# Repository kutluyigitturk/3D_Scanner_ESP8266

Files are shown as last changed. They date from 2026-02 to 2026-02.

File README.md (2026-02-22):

<div align="center">

# 3D_Scanner_ESP8266






**A real-time 3D point cloud scanner over WiFi using Arduino Uno, ESP8266 and VL53L0X laser distance sensor.**

</div>

---

## Hardware

| Component | Quantity |
|---|---|
| Arduino Uno | 1 |
| ESP8266-01S WiFi Module | 1 |
| VL53L0X Laser Distance Sensor | 1 |
| MG90S Servo Motor (Pan,Tilt) | 2 |
| AMS1117 3.3V Voltage Regulator Module | 1 |
| USB to TTL - CP2102 | 1 |
| 3D Printing Chasis | 1 |

---

## Wiring

| Component | Arduino Pin | Note |
|---|---|---|
| Servo Pan | D9 | PWM |
| Servo Pan | 5V | Power |
| Servo Pan | GND | Ground |
| Servo Tilt | D10 | PWM |
| Servo Tilt | 5V | Power |
| Servo Tilt |GND | Ground |
| VL53L0X SDA | A4 | I2C Data |
| VL53L0X SCL | A5 | I2C Clock |
| VL53L0X VIN | 3V3 | Power |
| VL53L0X GND | GND | Ground |
| ESP8266 RX | D3 (SoftSerial TX) | Direct connection |
| ESP8266 TX | D2 (SoftSerial RX) | Direct connection |
| ESP8266 CH_PD,VCC | 3V3 | Power |
| ESP8266 GND | GND | Ground |

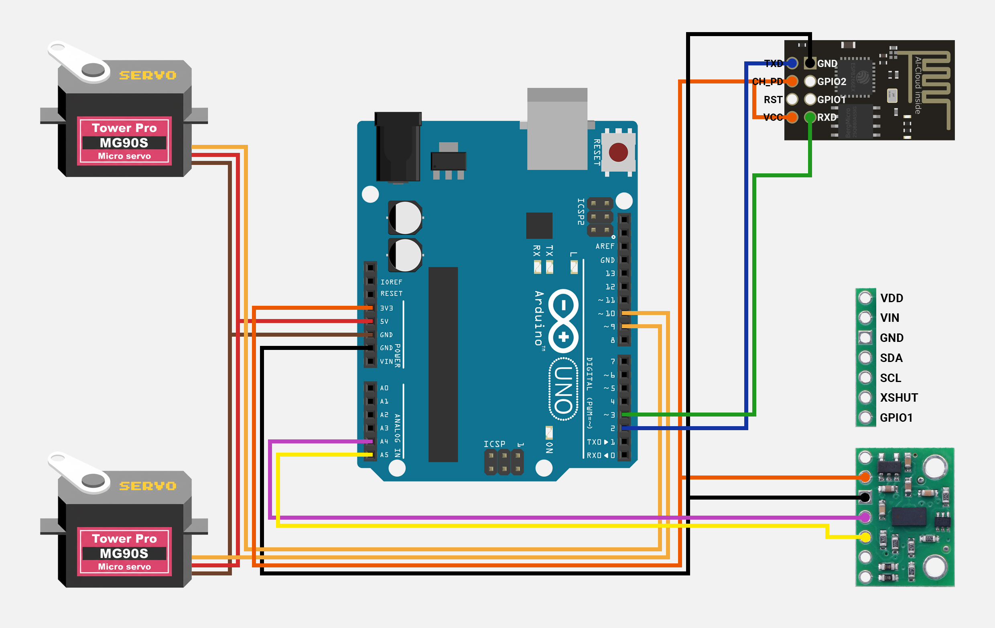
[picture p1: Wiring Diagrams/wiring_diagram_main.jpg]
Main Wiring Diagram


---

## Setup

### 1. Libraries

Install the following libraries via Arduino IDE Library Manager:

- `VL53L0X` — Pololu
- `Servo` — Arduino Built-in
- `SoftwareSerial` — Arduino Built-in
- `ESP8266WiFi` — ESP8266 Community
- `ESP8266WebServer` — ESP8266 Community
- `LittleFS` — ESP8266 Community

### 2. ESP8266 Board Support

Go to **File > Preferences > Additional Board Manager URLs** and add:

```
https://arduino.esp8266.com/stable/package_esp8266com_index.json
```

Then install the `esp8266` package from **Tools > Board Manager**.

### 3. Flash Size

Before uploading to ESP8266, set:

**Tools > Flash Size > `4MB (FS:2MB OTA:~1MB)`**

LittleFS requires a dedicated flash partition to store scan data.

### 4. Upload Order

Upload `ESP8266_Server.ino` to the ESP8266 first, then upload `Uno_Controller.ino` to the Arduino Uno.

---

## Usage

1. Power on the system — the ESP8266 will create a WiFi access point named **`3D_Scanner_Project`**.
2. Connect your phone or computer to this network. Password: **`12345678`**
3. Open a browser and go to **`192.168.4.1`**.
4. Navigate to **`192.168.4.1/scan`** to start a scan.
5. Once the scan is complete, return to the main page — the point cloud will be rendered in WebGL.

### Endpoints

| Address | Function |
|---|---|
| `/scan` | Starts a new scan |
| `/status` | Returns current status as JSON |
| `/reset` | Clears previous scan data |
| `/format` | Formats the LittleFS filesystem |

---

## Adjusting Pan-Tilt Angles

You can customize the scan area by editing the configuration block at the top of `Uno_Controller.ino`:

```cpp
const int YAW_MIN  = 0;   // Pan start angle  (°)
const int YAW_MAX  = 80;  // Pan end angle    (°)
const int PITCH_MIN = 0;  // Tilt start angle (°)
const int PITCH_MAX = 90; // Tilt end angle   (°)

const int STEP_YAW   = 2; // Step size — smaller = more points, slower scan
const int STEP_PITCH = 2;

const float VALID_MIN = 0.04f; // Valid distance range (meters)
const float VALID_MAX = 0.30f;
```

---

## Flashing the ESP8266-01S

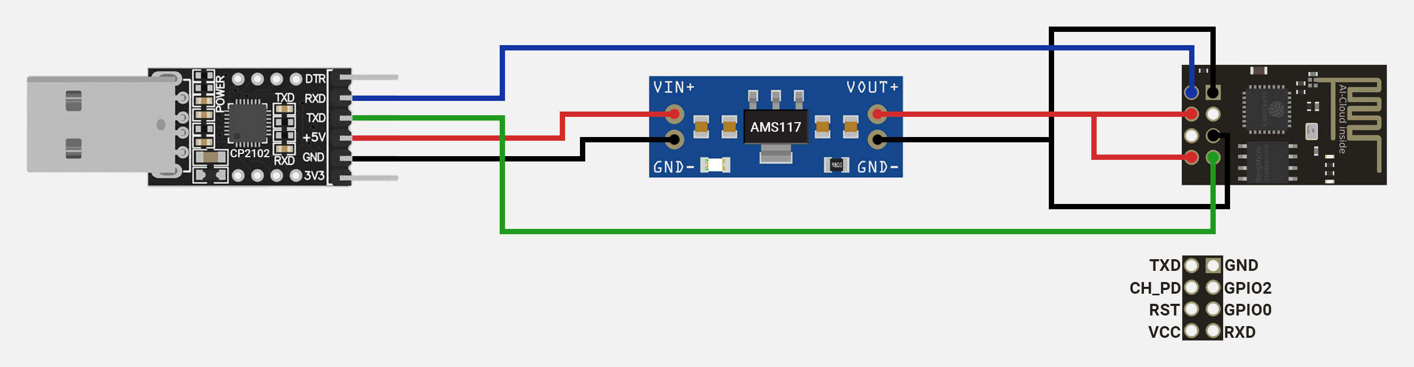
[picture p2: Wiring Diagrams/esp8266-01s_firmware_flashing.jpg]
ESP8266-01S Flashing Setup


### ESP8266-01S Firmware Flashing Procedure
This section details the hardware setup required to flash custom firmware onto the ESP8266-01S using the Arduino IDE. Due to the minimal pin output of the ESP-01S, a special USB-TTL serial converter is required for programming.

#### Critical Power Supply Considerations
Most USB-TTL converters provide a maximum of 50–100mA from the 3.3V pin, but the ESP8266-01S can draw up to 170–300mA during programming. Insufficient current causes:
- Brownout reset (continuous reset due to voltage drop)
- Connection drops during firmware upload
- "Failed to connect to ESP8266" errors
- Risk of permanent damage to the module

#### AMS1117-3.3 Regulator Solution
The AMS1117-3.3 linear voltage regulator solves this by providing a stable 3.3V/800mA from the 5V USB supply.

**Key connections:**

1. **GND** — Connect ESP-01S GND to AMS1117 GND.
2. **VCC & CH_PD** — Connect ESP-01S VCC and CH_PD (Chip Enable) to AMS1117 VOUT+.
   > ⚠️ Do **not** power the ESP-01S directly from the USB-TTL adapter's 3.3V pin — it cannot supply sufficient current.
3. **TX/RX** — Cross-connect the serial lines:
   - ESP-01S `TXD` → USB-TTL `RXD`
   - ESP-01S `RXD` → USB-TTL `TXD`
4. **Flashing Mode** — Connect ESP-01S `GPIO0` directly to GND. This puts the module into bootloader mode, ready to receive new firmware.

---

## 3D Printable Parts

The `3D Printable Parts/` folder contains all parts needed to assemble the scanner mechanism.

The tripod used in this project is sourced from:
**[Folding Tripod — MakerWorld](https://makerworld.com/tr/models/671280-folding-tripod-two-sizes?from=search#profileId-599018)**

---

## Inspiration

This project is inspired by the original ESP8266 3D scanner by **[bitluni](https://bitluni.net/3d-scanner)**.

---

## License

This project is licensed under the [MIT License](LICENSE).

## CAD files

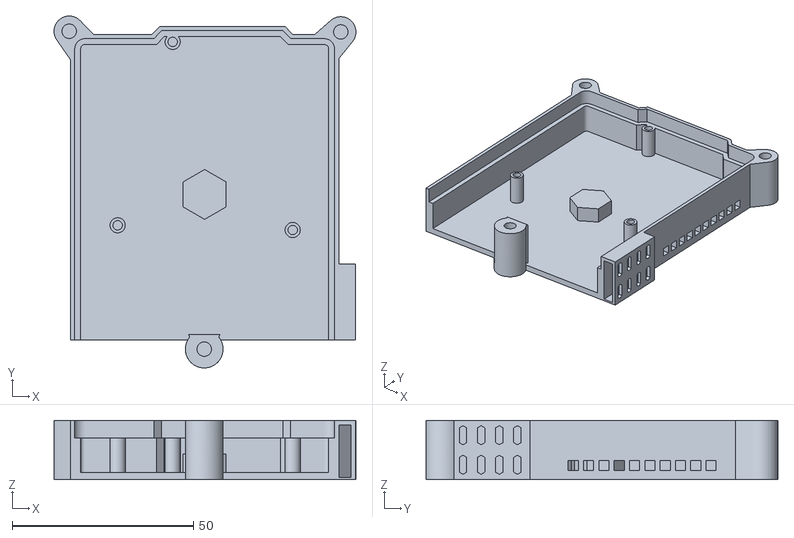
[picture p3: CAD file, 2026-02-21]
3D Printable Parts/Base.stl
83.3 x 97.0 x 16.3

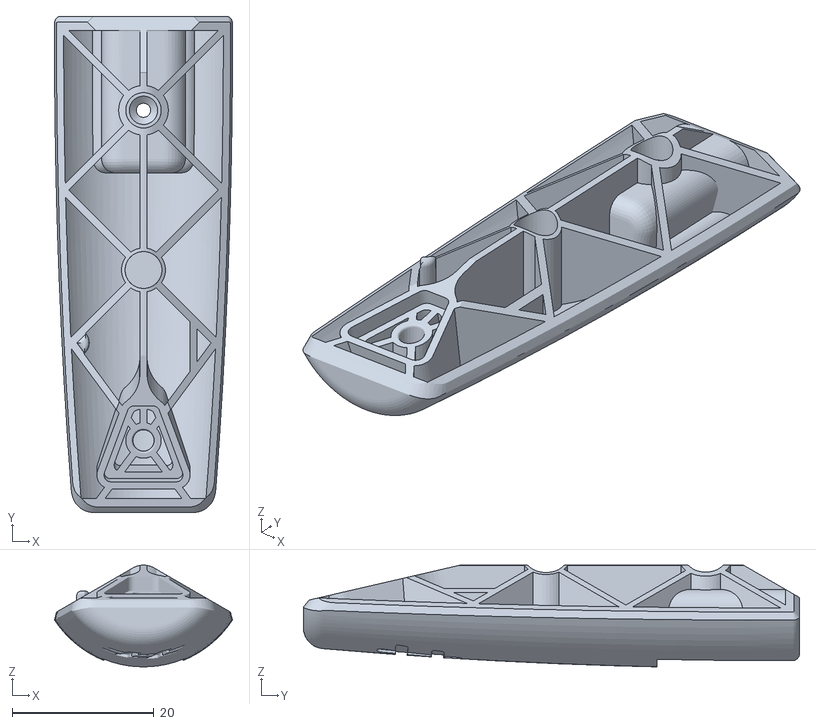
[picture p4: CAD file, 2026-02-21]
3D Printable Parts/Tripod/Leg_small.stl
25.1 x 70.0 x 14.4

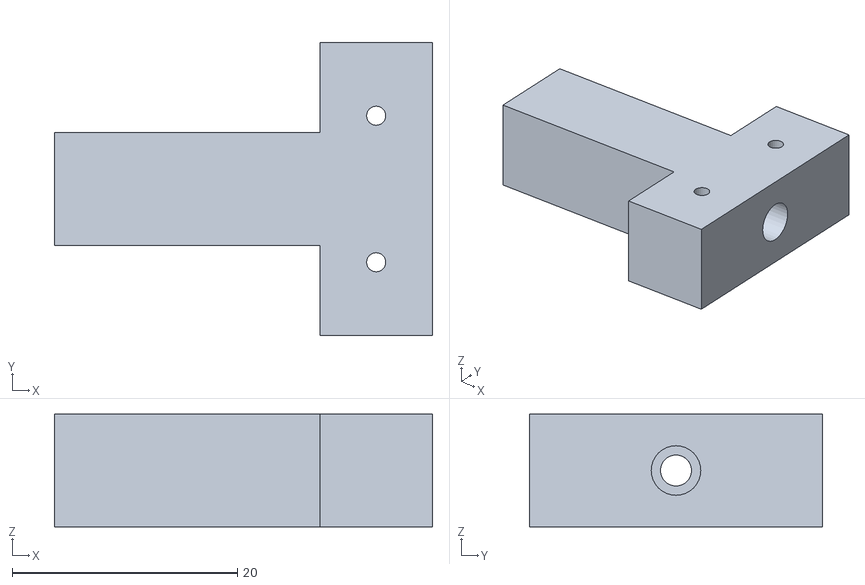
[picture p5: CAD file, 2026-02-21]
3D Printable Parts/Laser Sensor Mount.stl
33.5 x 26.0 x 10.0

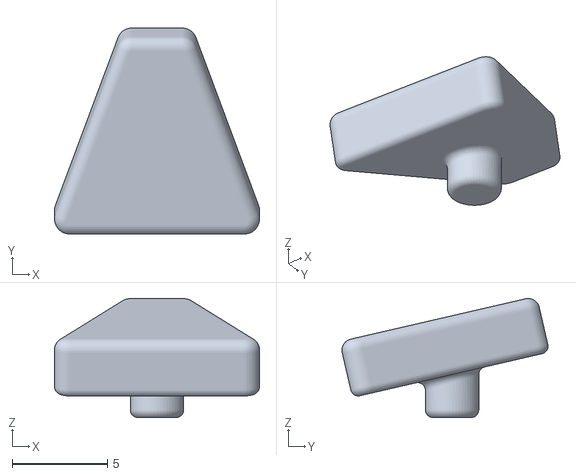
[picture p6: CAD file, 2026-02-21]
3D Printable Parts/Tripod/Foot Pad.stl
10.7 x 10.8 x 6.24

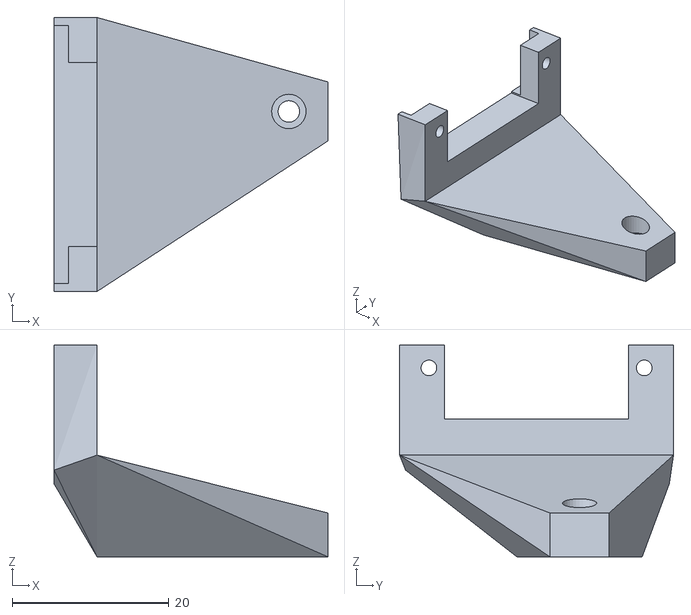
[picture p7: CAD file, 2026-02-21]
3D Printable Parts/Tilt Servo Mount.stl
35.0 x 35.0 x 27.0

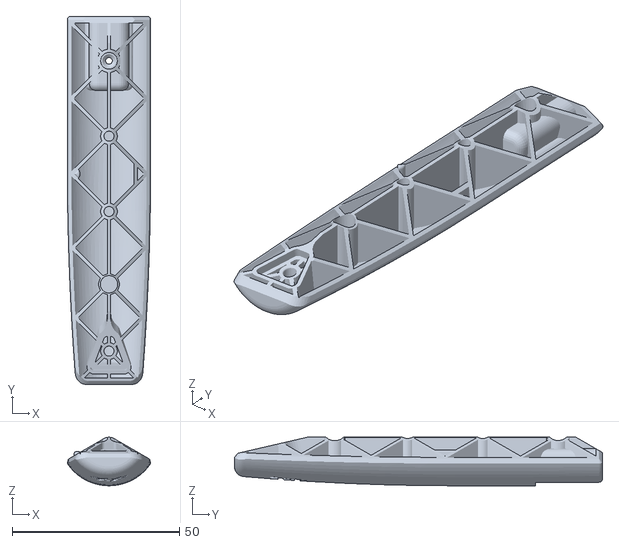
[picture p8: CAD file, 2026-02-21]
3D Printable Parts/Tripod/LegLarge.stl
24.9 x 110.0 x 14.5

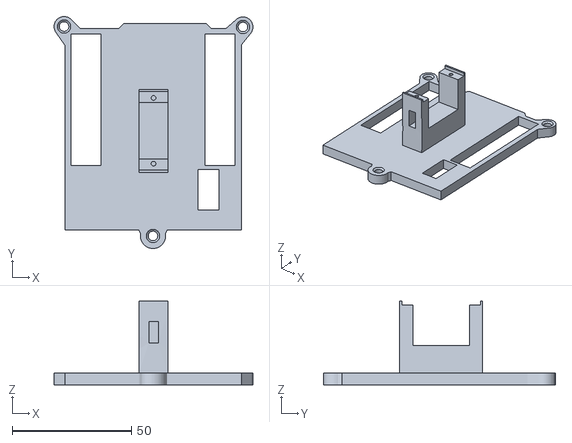
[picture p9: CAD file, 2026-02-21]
3D Printable Parts/Top.stl
83.3 x 97.1 x 35.0

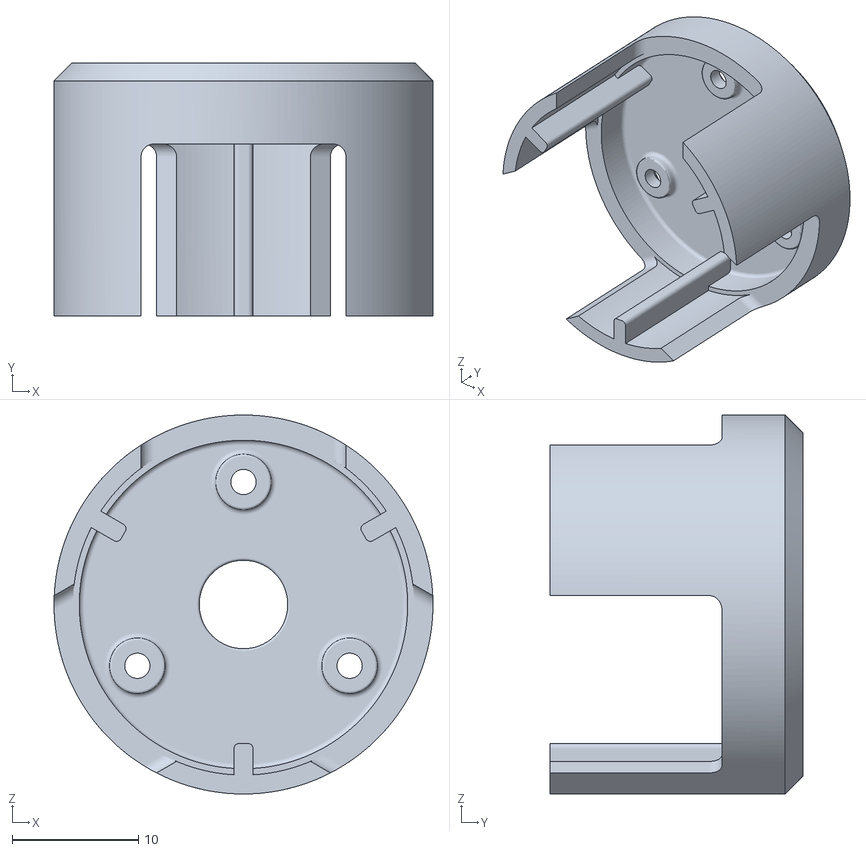
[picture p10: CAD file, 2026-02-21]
3D Printable Parts/Tripod/Cover.stl
30.0 x 20.0 x 30.0

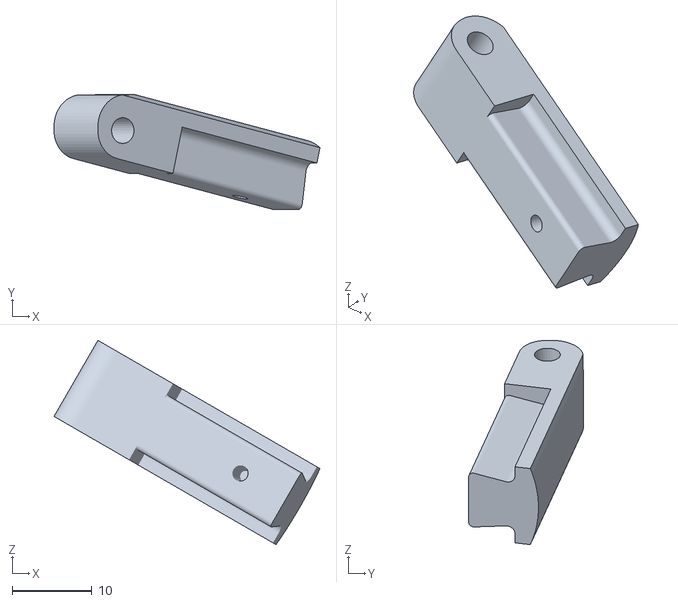
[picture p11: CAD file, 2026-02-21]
3D Printable Parts/Tripod/Stud.stl
33.3 x 14.4 x 25.6

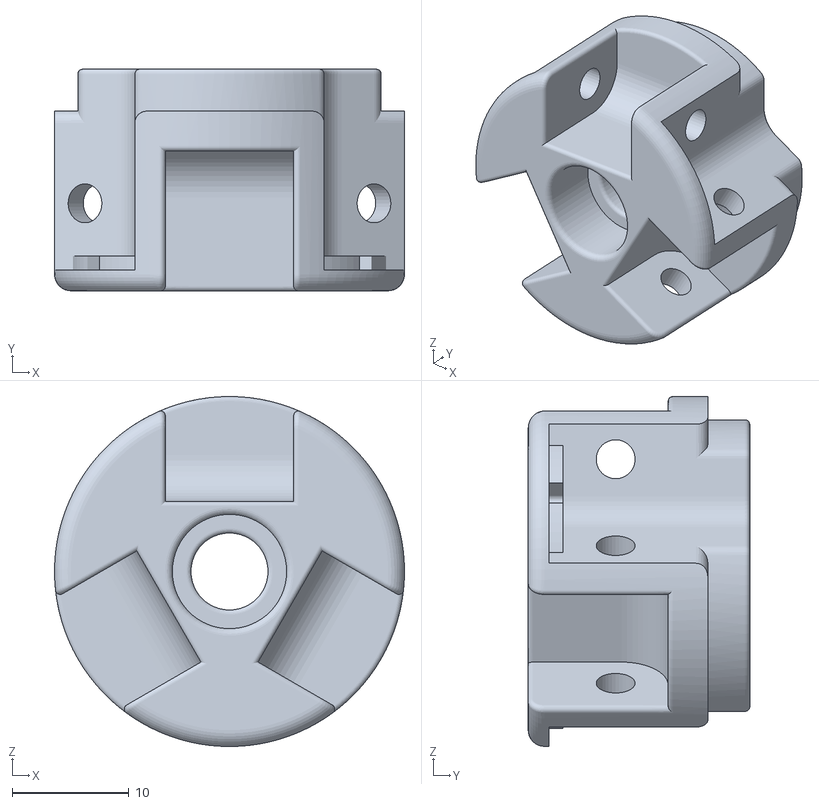
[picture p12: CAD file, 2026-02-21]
3D Printable Parts/Tripod/Center.stl
30.0 x 19.0 x 30.0

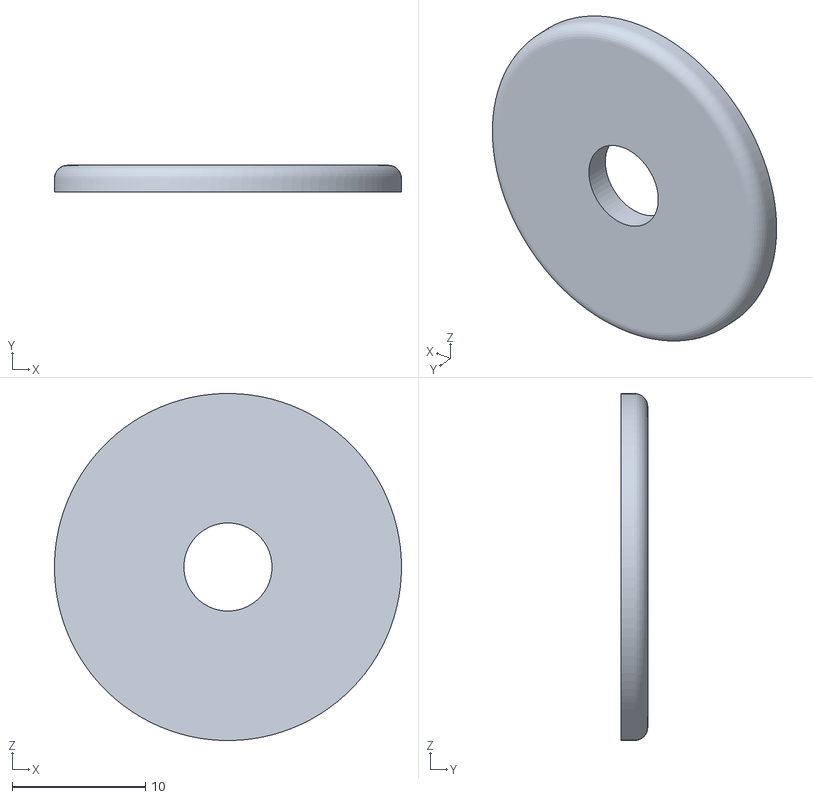
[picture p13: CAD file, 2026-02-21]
3D Printable Parts/Tripod/TPU_pad.stl
26.0 x 2.00 x 26.0

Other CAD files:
3D Printable Parts/Tripod/LegLargeBolt.stl
3D Printable Parts/Tripod/Leg_Small_Bolt.stl

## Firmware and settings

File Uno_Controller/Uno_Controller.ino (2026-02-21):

/*
 * ============================================================
 *  3D SCANNER — Arduino Uno Controller
 *
 *  [1] Angle settings moved into a clean CONFIGURATION block.
 *  [2] ADAPTIVE MEDIAN FILTER:
 *      - Empty area (no object) → 1 fast reading, discard if invalid.
 *      - Object detected        → take 3 readings, return median.
 *      Empty areas are swept quickly while object accuracy is preserved.
 *
 *  WIRING:
 *    Servo Yaw   → D9    Servo Pitch → D10
 *    VL53L0X SDA → A4    VL53L0X SCL → A5
 *    ESP8266 RX  ← D3    ESP8266 TX  → D2
 * ============================================================
 */

#include <Wire.h>
#include <VL53L0X.h>
#include <Servo.h>
#include <SoftwareSerial.h>

SoftwareSerial espSerial(2, 3);
VL53L0X sensor;
Servo yawServo;
Servo pitchServo;

// ╔══════════════════════════════════════════════════════════╗
// ║              >>> CONFIGURE HERE <<<                      ║
// ╠══════════════════════════════════════════════════════════╣
// ║  Pan (horizontal) and Tilt (vertical) angle limits       ║
// ║  Servos physically operate between 0–180°.               ║
// ║  Narrow the range with MIN/MAX to skip unwanted areas.   ║
// ╚══════════════════════════════════════════════════════════╝

const int YAW_MIN   = 0;    // Pan start angle  (°)  ← CHANGE
const int YAW_MAX   = 90;   // Pan end angle    (°)  ← CHANGE
const int PITCH_MIN = 40;   // Tilt start angle (°)  ← CHANGE
const int PITCH_MAX = 110;  // Tilt end angle   (°)  ← CHANGE

// Step size: smaller = more points but slower scan
const int STEP_YAW   = 1;  // (°)  ← CHANGE
const int STEP_PITCH = 1;  // (°)  ← CHANGE

// Valid distance window (meters) — readings outside this range are discarded
const float VALID_MIN = 0.04f;  // (m)  ← CHANGE
const float VALID_MAX = 0.30f;  // (m)  ← CHANGE

// ── Coordinate offsets (do not touch) ────────────────────────
// These define the mathematical origin for 3D coordinate calculation.
// They affect output coordinates, not physical servo angles.
const float YAW_OFFSET    = -40.0f;
const float PITCH_OFFSET  = -45.0f;
const float SENSOR_OFFSET = 0.012f;  // Mechanical mounting offset (m)

// ── Timing ───────────────────────────────────────────────────
const int PIN_YAW     = 9;
const int PIN_PITCH   = 10;
const int SETTLE_MS   = 60;
const int SERIAL_WAIT = 25;

int currentYaw   = 40;
int currentPitch = 45;

// ── Detach PWM, send data, re-attach ─────────────────────────
void safeSend(const String& data) {
  yawServo.detach();
  pitchServo.detach();

  espSerial.println(data);
  delay(SERIAL_WAIT);

  yawServo.attach(PIN_YAW);
  pitchServo.attach(PIN_PITCH);
  yawServo.write(currentYaw);
  pitchServo.write(currentPitch);
  delay(10);
}

void moveYaw(int pos)   { currentYaw = pos;   yawServo.write(pos); }
void movePitch(int pos) { currentPitch = pos; pitchServo.write(pos); }

// ── Adaptive median-filtered sensor reading ───────────────────
//
//  STEP 1 — Fast pre-scan (1 reading):
//    If invalid (empty area), return -1 immediately → fast iteration.
//
//  STEP 2 — Object detected, take 2 more readings:
//    Return the median of all 3 → noise suppressed.
//
//  Empty area : ~70ms  (1 × 66ms budget)
//  Object hit : ~210ms (3 × 66ms budget + 2 × 5ms delay)
//
float readFiltered() {
  // ── Step 1: Fast pre-reading ──────────────────────────────
  float first = sensor.readRangeSingleMillimeters() * 0.001f;

  if (sensor.timeoutOccurred() || first < VALID_MIN || first > VALID_MAX) {
    return -1.0f;  // Empty area → exit fast
  }

  // ── Step 2: Object found, take 2 more readings (3 total) ─
  float buf[3];
  buf[0] = first;
  int cnt = 1;

  for (int i = 0; i < 2; i++) {
    delay(5);
    float d = sensor.readRangeSingleMillimeters() * 0.001f;
    if (!sensor.timeoutOccurred() && d >= VALID_MIN && d <= VALID_MAX)
      buf[cnt++] = d;
  }

  if (cnt == 1) return buf[0];  // Other readings invalid, use the first one

  // Simple sort → median
  for (int i = 0; i < cnt - 1; i++)
    for (int j = i + 1; j < cnt; j++)
      if (buf[j] < buf[i]) { float t = buf[i]; buf[i] = buf[j]; buf[j] = t; }

  return buf[cnt / 2];
}

// ── Cartesian conversion ──────────────────────────────────────
String buildPoint(int yaw, int pitch, float dist) {
  float yr = (yaw   + YAW_OFFSET)   * (M_PI / 180.0f);
  float pr = (pitch + PITCH_OFFSET)  * (M_PI / 180.0f);
  float od = SENSOR_OFFSET + dist;
  float x  = -sin(yr) * od * cos(pr);
  float y  =  cos(yr) * od * cos(pr);
  float z  =  od * sin(pr);
  return String(x, 4) + "," + String(y, 4) + "," + String(z, 4);
}

// ── Main Scan ─────────────────────────────────────────────────
void scan() {
  Serial.println(F("[UNO] Scan starting"));
  safeSend("START");

  bool hasPending = false;
  String pending  = "";

  for (int yaw = YAW_MIN; yaw <= YAW_MAX; yaw += STEP_YAW) {
    moveYaw(yaw);

    if (hasPending) {
      delay(10);
      safeSend(pending);
      hasPending = false;
      delay(SETTLE_MS - 10);
    } else {
      delay(SETTLE_MS);
    }

    for (int pitch = PITCH_MIN; pitch <= PITCH_MAX; pitch += STEP_PITCH) {
      movePitch(pitch);

      if (hasPending) {
        delay(10);
        safeSend(pending);
        hasPending = false;
        delay(SETTLE_MS - 10);
      } else {
        delay(SETTLE_MS);
      }

      float d = readFiltered();
      if (d > 0) {
        pending    = buildPoint(yaw, pitch, d);
        hasPending = true;
        Serial.print(F("Y:")); Serial.print(yaw);
        Serial.print(F(" P:")); Serial.print(pitch);
        Serial.print(F(" D:")); Serial.println(d, 3);
      }
    }
  }

  if (hasPending) safeSend(pending);

  delay(50);
  safeSend("END");
  moveYaw((YAW_MIN + YAW_MAX) / 2);
  movePitch((PITCH_MIN + PITCH_MAX) / 2);
  Serial.println(F("[UNO] Scan complete"));
}

void setup() {
  Serial.begin(115200);
  espSerial.begin(9600);
  Wire.begin();

  sensor.setTimeout(500);
  if (!sensor.init()) {
    Serial.println(F("[UNO] VL53L0X not found!"));
    while (1) delay(500);
  }
  sensor.setMeasurementTimingBudget(66000);

  yawServo.attach(PIN_YAW);
  pitchServo.attach(PIN_PITCH);
  moveYaw((YAW_MIN + YAW_MAX) / 2);
  movePitch((PITCH_MIN + PITCH_MAX) / 2);
  delay(1500);

  Serial.println(F("[UNO] Ready. Waiting for SCAN command from ESP..."));
}

void loop() {
  if (espSerial.available()) {
    String cmd = espSerial.readStringUntil('\n');
    cmd.trim();
    if (cmd == "SCAN") {
      Serial.println(F("[UNO] SCAN received"));
      scan();
    }
  }
}

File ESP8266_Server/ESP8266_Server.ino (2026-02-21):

/*
 * ============================================================
 *  3D SCANNER — ESP8266 WiFi Server
 *
 *  [1] SPIFFS WRITE ERROR FIX:
 *      - SPIFFS removed entirely, replaced with LittleFS.
 *        (SPIFFS is deprecated in ESP8266 Arduino Core 3.x)
 *      - If LittleFS.begin() fails, filesystem is auto-formatted.
 *  [2] LIVE STREAMING:
 *      - New points are buffered in RAM.
 *      - /newpoints endpoint returns buffered points and clears the buffer.
 *      - Renderer.h polls /newpoints every 2 seconds and dynamically
 *        appends incoming points to the WebGL buffer.
 *  [3] File kept open (inherited from v2.0): opened on START, closed on END.
 *
 *  SETUP NOTE:
 *  Arduino IDE → Tools → Flash Size → "4MB (FS:2MB OTA:~1MB)"
 *  No separate "ESP8266 LittleFS Data Upload" tool needed;
 *  files are created entirely by the firmware.
 * ============================================================
 */

#include <ESP8266WiFi.h>
#include <ESP8266WebServer.h>
#include <LittleFS.h>
#include "Renderer.h"

ESP8266WebServer server(80);

// ─── State ───────────────────────────────────────────────────
enum ScanState { IDLE, SCANNING, DONE, FS_ERROR };
ScanState scanState  = IDLE;
int       pointCount = 0;

// ─── RAM buffer for live streaming ───────────────────────────
// Each point is "x,y,z" ~20 chars. 100 points = ~2KB → safe.
const int  LIVE_BUF_SIZE = 100;
String     liveBuf[LIVE_BUF_SIZE];
int        liveBufHead  = 0;  // Write index
int        liveBufTail  = 0;  // Read index
int        liveBufCount = 0;

void livePush(const String& point) {
  if (liveBufCount < LIVE_BUF_SIZE) {
    liveBuf[liveBufHead] = point;
    liveBufHead = (liveBufHead + 1) % LIVE_BUF_SIZE;
    liveBufCount++;
  }
  // If buffer is full, oldest data is dropped (graceful degradation)
}

// ─── File handle ─────────────────────────────────────────────
File dataFile;
bool fileOpen = false;

void safeCloseFile() {
  if (fileOpen && dataFile) {
    dataFile.close();
    fileOpen = false;
  }
}

// ─── /  Main page ─────────────────────────────────────────────
void handleRoot() {
  server.send(200, "text/html", renderer);
}

// ─── /vertices.js  Completed point cloud ──────────────────────
void handleVertices() {
  if (scanState == SCANNING || scanState == IDLE) {
    // Scan not finished or not yet started — return empty array
    server.send(200, "application/javascript",
      "var vertices = new Float32Array([]);");
    return;
  }
  if (!LittleFS.exists("/distance.js")) {
    server.send(200, "application/javascript",
      "var vertices = new Float32Array([]);");
    return;
  }
  File f = LittleFS.open("/distance.js", "r");
  if (!f) {
    server.send(200, "application/javascript",
      "var vertices = new Float32Array([]);");
    return;
  }
  server.streamFile(f, "application/javascript");
  f.close();
}

// ─── /newpoints  Polling endpoint for live streaming ─────────
// Returns buffered new points as a JSON array and clears the buffer.
// Renderer.h polls this every 2 seconds.
void handleNewPoints() {
  String json = "[";
  int count = 0;
  while (liveBufCount > 0) {
    if (count > 0) json += ",";
    json += "\"" + liveBuf[liveBufTail] + "\"";
    liveBufTail  = (liveBufTail + 1) % LIVE_BUF_SIZE;
    liveBufCount--;
    count++;
  }
  json += "]";

  // Cache-Control header to prevent browser caching
  server.sendHeader("Cache-Control", "no-cache");
  server.send(200, "application/json", json);
}

// ─── /scan  Start scan ────────────────────────────────────────
void handleScan() {
  if (scanState == SCANNING) {
    server.send(409, "text/plain", "Scan already in progress.");
    return;
  }
  if (scanState == FS_ERROR) {
    server.send(500, "text/plain",
      "Filesystem error. Please go to /format to reformat.");
    return;
  }
  Serial.println("SCAN");  // Send command to Arduino
  server.send(200, "text/plain", "OK");
}

// ─── /status  JSON status ─────────────────────────────────────
void handleStatus() {
  const char* states[] = {"idle", "scanning", "done", "fs_error"};
  String json = "{\"state\":\"";
  json += states[(int)scanState];
  json += "\",\"points\":";
  json += pointCount;
  json += ",\"buffered\":";
  json += liveBufCount;
  json += "}";
  server.send(200, "application/json", json);
}

// ─── /reset  Clear previous scan data ────────────────────────
void handleReset() {
  if (scanState == SCANNING) {
    server.send(409, "text/plain", "Scan in progress. Cannot reset.");
    return;
  }
  safeCloseFile();
  LittleFS.remove("/distance.js");
  scanState    = IDLE;
  pointCount   = 0;
  liveBufHead  = liveBufTail = liveBufCount = 0;
  server.send(200, "text/plain", "Reset complete. Use /scan to start a new scan.");
}

// ─── /format  Format LittleFS (emergency use) ─────────────────
void handleFormat() {
  safeCloseFile();
  bool ok = LittleFS.format();
  if (ok && LittleFS.begin()) {
    scanState = IDLE;
    server.send(200, "text/plain", "Format successful.");
  } else {
    server.send(500, "text/plain", "Format failed. Possible hardware issue.");
  }
}

// ─── Setup ───────────────────────────────────────────────────
void setup() {
  Serial.begin(9600);

  // Initialize LittleFS — auto-format if it fails
  if (!LittleFS.begin()) {
    // Format on first use or corrupted filesystem
    LittleFS.format();
    if (!LittleFS.begin()) {
      scanState = FS_ERROR;
      // Server will still run, /format endpoint remains active
    }
  }

  WiFi.softAP("3D_Scanner_Project", "12345678");

  server.on("/",            handleRoot);
  server.on("/vertices.js", handleVertices);
  server.on("/newpoints",   handleNewPoints);
  server.on("/scan",        handleScan);
  server.on("/status",      handleStatus);
  server.on("/reset",       handleReset);
  server.on("/format",      handleFormat);

  server.begin();
}

// ─── Loop ────────────────────────────────────────────────────
void loop() {
  server.handleClient();

  if (Serial.available()) {
    String data = Serial.readStringUntil('\n');
    data.trim();
    if (data.length() == 0) return;

    if (data == "START") {
      safeCloseFile();
      if (scanState != FS_ERROR) {
        dataFile = LittleFS.open("/distance.js", "w");
        if (dataFile) {
          dataFile.print("var vertices = new Float32Array([");
          fileOpen = true;
        } else {
          scanState = FS_ERROR;
          return;
        }
      }
      scanState    = SCANNING;
      pointCount   = 0;
      liveBufHead  = liveBufTail = liveBufCount = 0;
    }

    else if (data == "END") {
      if (fileOpen) {
        dataFile.print("]);");
        safeCloseFile();
      }
      scanState = DONE;
    }

    else if (data.indexOf(',') != -1 && scanState == SCANNING) {
      // Write to LittleFS
      if (fileOpen) {
        dataFile.print(data);
        dataFile.print(",");
        if (pointCount % 50 == 0) dataFile.flush();
      }
      // Push to live buffer
      livePush(data);
      pointCount++;
    }
  }
}

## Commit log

2026-02-21 3D Print Files Have Been Added
    [Base.stl, Center.stl, Cover.stl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]
2026-02-21 docs: add project README with hardware setup, wiring diagram and usage guide
2026-02-21 v0.1: add Arduino Uno controller, ESP8266 WiFi server and WebGL renderer
2026-02-22 docs: add ESP8266-01S flashing procedure and wiring diagram
2026-02-22 docs: add main wiring diagram to README

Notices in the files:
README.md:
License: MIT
